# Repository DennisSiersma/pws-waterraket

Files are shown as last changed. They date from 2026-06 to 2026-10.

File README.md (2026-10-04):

# PWS Waterraket

Profielwerkstuk natuurkunde (vwo): welke factoren bepalen de prestatie
(apogeumhoogte) van een waterraket? Met testplan, lanceerinstallatie,
meet-logsheets en een zelfgebouwde vluchtcomputer.

## Gekozen hardware (route B)

Vluchtcomputer: **Waveshare ESP32-S3-Touch-LCD-1.69** met een losse druksensor.
De eerdere XIAO-opzet is niet gekozen; die bestanden blijven staan als alternatief
en ter verantwoording van de keuze, maar worden niet onderhouden.

| Functie | Onderdeel | Adres |
|---|---|---|
| Microcontroller + scherm + touch | Waveshare ESP32-S3-Touch-LCD-1.69 | touch 0x15 |
| Versnelling (stuwprofiel) | QMI8658, onboard | 0x6B |
| Hoogte (apogeum) | BMP388 **of** BME680, los bijgeprikt | 0x76 / 0x77 |
| Voeding | 3,7 V LiPo met MX1.25-stekker | - |
| Fles (standaard) | Fernandes Cherry Bouquet 1,5 L | volledig cilindrisch, diameter 88,5 mm |

De firmware herkent bij het opstarten zelf welke druksensor er zit en stelt zich
daarop in. De BMP388 is de betere keuze voor de vluchten; de BME680 werkt ook maar
is trager.

> **Bouw je dit na? Lees eerst [`docs/HANDLEIDING.md`](docs/HANDLEIDING.md).**
> Daarin staan de valkuilen die ons tijd hebben gekost: de CS/CSB-jumper op de
> sensor, de juiste USB-poort bij het flashen, de PWR-knop voor accuvoeding, en de
> koppeling tussen oversampling en meetfrequentie.

## Meetdata analyseren

Open [`webapp/index.html`](webapp/index.html) in een browser en sleep de CSV-bestanden
erop die je van de vluchtcomputer hebt gedownload. De applicatie draait volledig in
de pagina: geen server, geen bouwstap, geen internet. Ze berekent apogeum, snelheid,
versnelling, stuwtijd, vluchttijd en daalsnelheid met de bijbehorende meetonzekerheid,
vergelijkt vluchten op een instelvariabele, zet het theoretische model ernaast en
levert PNG's, een CSV en een afdrukbaar rapport voor in het verslag.

Bij elke berekende waarde staat de formule in de interface zelf. Ze staan ook
bij elkaar in [`docs/PWS_Waterraket_Analyse_Formules.md`](docs/PWS_Waterraket_Analyse_Formules.md),
geschikt als bijlage bij het profielwerkstuk.

Testdata met een exact bekende uitkomst en de volledige controlereeks:

```bash
node test/genereer_vlucht.js --alles && node test/gauntlet.js
```

## Inhoud

```
webapp/
  index.html                                           <- hier begint de analyse
  stijl.css
  js/kern/                                             rekenwerk: csv, filter, grootheden, theorie
  js/ui/                                               grafieken, opslag, export
test/
  genereer_vlucht.js                                   synthetische vluchten met bekende uitkomst
  gauntlet.js                                          de vaste controlereeks
  browsertest/index.html                               controles die een browser nodig hebben
docs/
  PWS_Waterraket_Analyse_Formules.md                   Formules en aannames van de analyse
  HANDLEIDING.md                                       Bouw, gebruik en probleemoplossing
  PWS_Waterraket_Onderzoeksplan.docx                   Onderzoeksplan (theorie, testplan, BOM)
  PWS_Waterraket_Lanceerinstallatie.docx               Launcher: tekening, onderdelen, bronnen
  PWS_Waterraket_Bouwtekening_Launcher_SplitCollar.svg Detailtekening launcher (split-collar, aanbevolen)
  PWS_Waterraket_Bouwtekening_Launcher_Clark.svg       Detailtekening launcher (schuifkraag, oudere variant)
  PWS_Waterraket_Bouwtekening_Lanceerinstallatie.svg   Overzichtstekening launcher
  PWS_Waterraket_Bedradingsschema_S3-Touch.svg         Bedrading van de gekozen opstelling
  PWS_Waterraket_Bedradingsschema_XIAO.svg             (alternatief, niet gebruikt)
firmware/
  PWS_Waterraket_ESP32-S3-Touch_sketch.ino             <- deze gebruiken
  PWS_Waterraket_ESP32_sketch.ino                      (alternatief, niet gebruikt)
hardware/
  PWS_Waterraket_Houder.stl                            Payloadhouder (bord + sensor + accu)
  PWS_Waterraket_Vinnen_klein/midden/groot.stl         Fin can, drie maten met bekend vinoppervlak
  PWS_Waterraket_Recovery_Romp.stl / _Deur.stl         Recovery: parachutekamer met servo-zijdeur
  PWS_Waterraket_Recovery_Schot_A/B.stl                Los schotje in twee helften (past zo door de draad)
  PWS_Waterraket_Tray_A/B.stl                          Elektronicatray in twee helften: A bord, B accu+sensor
  PWS_Waterraket_Neus_Ogief/Kegel/Elliptisch.stl       Verwisselbare schroefneuzen, drie vormen
  PWS_Waterraket_Testneus.stl                          Simpele TPU-neus voor testvluchten zonder parachute
  PWS_Waterraket_NozzleOpzet_04..09mm.stl              Nozzles: opzetstuk over de originele dop (voorkeur)
  PWS_Waterraket_NozzleLijm_04..09mm.stl               Nozzles: op de originele dop te lijmen
  PWS_Waterraket_NozzleSteunring_04..09mm.stl          Nozzles, 4 t/m 9 mm (zitting op de steunring)
  archief/                                             niet gebruikte ontwerpen, met uitleg waarom
  genereer_*.py                                        Generatorscripts (maten bovenin aanpasbaar)
logsheets/
  PWS_Waterraket_Logsheets.xlsx                        Vluchtlog + hoogte-/spreidingsberekening
```

## Bediening in het kort

| Scherm | BOOT kort | BOOT lang |
|---|---|---|
| HOME | INFO | START (kalibreren + scherp) |
| INFO | terug | raaktest |
| Raaktest | terug | ijken (>4 s: ijking wissen) |

Na de vlucht opent VERZEND een wifi-netwerk (`Waterraket` / `raket1234`) waarop je
de meting als CSV downloadt. Het INFO-scherm toont live druk, hoogte, temperatuur
en versnelling, zodat je kunt testen zonder te lanceren.

## Meetmethode

Primair: barometrische apogeumhoogte, gevalideerd met de trigonometrische
grondmeting (hoek + afstand). De QMI8658 geeft het versnellings- en stuwprofiel.

## Veiligheid

Alleen frisdrank-PET-flessen; begin laag (3-4 bar), nooit boven ~7 bar; minimaal
10 m afstand, lanceren via een touw, veiligheidsbril. 3D-geprinte drukdelen eerst
vol water achter een afscherming testen. LiPo's alleen onder toezicht laden en de
polariteit controleren vóór het insteken.

## Bronnen

De volledige bronnenlijst staat in het hoofdstuk "Bronnen" van het onderzoeksplan.

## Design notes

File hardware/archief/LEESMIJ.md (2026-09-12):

# Archief: niet gebruikte ontwerpen

Deze bestanden zijn NIET in gebruik. Ze staan hier bewaard omdat ze de
ontwerpstappen laten zien, en dat is verantwoording waard in het verslag.
Print hieruit niets; de werkende versies staan een map hoger.

## Nozzles: vier varianten die het niet werden

De eis was dat de nozzle kaarsrecht op de fles staat. Een scheve nozzle geeft
scheve stuwkracht en dus een raket die niet zuiver vliegt.

| Bestanden | Aanpak | Waarom afgevallen |
|---|---|---|
| `PWS_Waterraket_Nozzle_04..10mm.stl` | insteek in een geboorde originele dop | goede aanpak, maar past niet in onze Gardena-launcher |
| `PWS_Waterraket_Nozzledop_*.stl` | volledig geprinte dop met PCO1881-draad | de geprinte draad bepaalt de stand en die staat scheef |
| `PWS_Waterraket_NozzleGardena_*.stl` | Gardena-steel plus geleidingspen in de flesmond | de pen maakt een diepe sleuf waar support in moet dat je er niet uit krijgt |
| `PWS_Waterraket_NozzleGardenaDop_*.stl` | Gardena-steel in een geboorde originele dop | werkbaar alternatief, maar nooit getest; de steunring-versie was beter |

De gemene deler van de mislukkingen: telkens werd de schroefdraad meegeprint, en
de vier losse draadsegmenten van een PCO1881-hals zijn gemaakt om aan te trekken,
niet om iets haaks te positioneren.

**Wat het wel werd:** `PWS_Waterraket_NozzleSteunring_*.stl`, met een zitting op
de steunring van de fles (33,07 mm in plaats van 21,74 mm), waardoor de zitting
veel breder is en de geleidingspen overbodig werd.

## Ook vervallen

- De losse neuskegel (bay en tip) is vervangen door de recovery-romp met
  verwisselbare schroefneus.
- De adapter naar het Raketfued Phoenix 3D-systeem is vervallen; dat principe is
  nagebouwd in de eigen parametrische pijplijn.

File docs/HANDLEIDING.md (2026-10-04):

# Handleiding vluchtcomputer waterraket

Praktische bouw-, gebruik- en probleemoplossingsgids voor de vluchtcomputer.
Alle hier genoemde instellingen staan bovenin `firmware/PWS_Waterraket_ESP32-S3-Touch_sketch.ino`.

## 1. Hardware

| Onderdeel | Keuze | Opmerking |
|---|---|---|
| Microcontroller | Waveshare ESP32-S3-Touch-LCD-1.69 | ESP32-S3R8, 240x280 LCD, CST816 touch |
| Versnelling | QMI8658 (onboard, 0x6B) | klipt bij +/-16 g tijdens de stuwfase |
| Hoogte | BMP388, BMP390(L) of BME680 (0x76/0x77) | firmware herkent ze automatisch |
| Voeding | 3,7 V LiPo, MX1.25-stekker | laden via USB-C |
| Fles | Fernandes Cherry Bouquet 1,5 L | volledig cilindrisch, diameter 88,5 mm |

De BMP388 is de betere keuze voor de vluchten (sneller, lagere ruis, gemaakt voor
hoogtemeting). De BME680 werkt ook, maar is trager omdat hij meer grootheden meet.

## 2. Solderen

Slechts vier draden tussen sensor en bord; de rest zit al op het bord.

| Sensor | Bord (randpad) |
|---|---|
| VCC | 3V3 (**niet** 5V) |
| GND | G |
| SDA | SDA (GPIO11) |
| SCL | SCL (GPIO10) |

Twee jumpers op de sensormodule zelf, en die zijn niet optioneel:

- **CSB (BMP388) / CS (BME680) naar VCC** - dwingt I2C af. Zwevend laten betekent
  dat de chip in SPI-modus blijft: hij geeft dan wel een acknowledge op de bus,
  maar levert alleen nullen (chip-ID 0x00). Dit heeft ons een sensor gekost die we
  ten onrechte voor defect hielden.
- **SDO naar GND (adres 0x76) of naar VCC (0x77)** - niet laten zweven.

Trek-ontlasting: een druppel hete lijm of een tiewrap over de draadbundel bij het
bord. Soldeerverbindingen op castellated pads breken anders bij de lanceerklap.

## 3. Flashen

Arduino IDE, board `ESP32S3 Dev Module`, PSRAM `OPI PSRAM`, `USB CDC On Boot:
Enabled`, flash 16MB.

Libraries: GFX Library for Arduino, SensorLib, Adafruit BMP3XX, Adafruit BME680
(+ Adafruit Unified Sensor en BusIO).

**Kies de juiste poort.** Dit bord heeft geen USB-serieel-chip: USB-C gaat
rechtstreeks naar de native USB van de ESP32-S3. Het meldt zich daarom als
*USB JTAG/serial debug unit*, bij ons `/dev/cu.usbmodem101`. Hangt er nog een
ander bord aan de Mac (met CH340/CH9102), dan verschijnt dat als *USB Single
Serial* en gaat de upload dáárheen: de upload slaagt, maar je raket-bord blijft
zijn oude firmware draaien. Bij twijfel het andere bord loskoppelen.

Blijft "Hard resetting via RTS pin..." staan: dat is normaal bij native USB (er is
geen RTS-lijn). Lukt de upload niet, houd dan **BOOT** ingedrukt, tik **RST** aan,
laat BOOT los.

## 4. Bediening

Bij het opstarten verschijnt kort een blauw **BOOT OK**-scherm met het
compileertijdstip. Zo weet je zeker dat de nieuwe firmware draait.

| Scherm | Touch | BOOT kort | BOOT lang (>1,2 s) |
|---|---|---|---|
| HOME | START / INFO | INFO | START (kalibreren + scherp) |
| INFO | TERUG | terug | raaktest |
| Raaktest | kruisje tekenen | terug | ijken (>4 s: ijking wissen) |

Vluchtverloop: START kalibreert (50 drukmetingen op de grond) en gaat naar GEREED.
Stijgt de hoogte boven 3 m, dan begint het loggen op 50 Hz naar intern flash.
Na de landing (of na 30 s) volgt het RESULTAAT-scherm met apogeum, maximale
versnelling en vluchttijd. Via VERZEND opent het bord een wifi-netwerk
(`Waterraket` / `raket1234`); daarop het getoonde IP-adres openen geeft de CSV.

## 5. Accu

Het bord start **niet** vanzelf op de accu. Sluit de accu aan en druk op de
**PWR-knop**; daarna houdt de firmware de voeding vast via SYS_EN (GPIO35 volgens
het schema; met `BOARD_ALT 1` schakel je naar GPIO41). Controleer de polariteit van
de MX1.25-stekker tegen de markering op het bord vóór het insteken.

## 6. Scherm en touch

- Het glas heeft **afgeronde hoeken**: houd tekst en knoppen binnen `SAFE_M` (22 px).
- `LCD_OFFY` hoort **20** te zijn. Met 0 loopt de titel van het scherm.
- De touch rapporteert y ongeveer **22 px hoger** dan waar je tikt. Dat is een vaste
  verschuiving en staat als standaard in de code (`calBy = -22`), geen schaalfout.
- De touch komt niet hoger dan ruw y=278, dus de onderste ~24 px zijn onbereikbaar.
  Alle knoppen staan daarom boven die grens.

## 7. Instellingen die bij elkaar moeten passen

Oversampling en meetfrequentie van de druksensor zijn gekoppeld. 8x oversampling
kost ongeveer 27 ms per meting en haalt 50 Hz (20 ms) niet: de sensor geeft dan een
configuratiefout en levert géén metingen. Daarom staat de druk op 4x en de
temperatuur op 1x.

## 8. Meetkundige aandachtspunten

- De hoogte op het INFO-scherm is gerekend tegen de standaarddruk van 1013,25 hPa
  en is dus **geen** hoogte boven de grond. Pas na kalibreren (START) is de hoogte
  relatief ten opzichte van het lanceerpunt.
- Kalibreer **vlak voor elke lancering**: de luchtdruk verandert gedurende de dag.
- Boor een klein **statisch gat** in de neuskegel ter hoogte van de sensor, zodat hij
  de omgevingsdruk meet en niet de dynamische druk van de luchtstroom.
- De versnellingsmeter klipt bij 16 g. Voor het apogeum maakt dat niet uit (daar is
  v ongeveer 0); voor het stuwprofiel is het een bekende beperking.

## 9. Payloadhouder (3D-print)

`hardware/PWS_Waterraket_Houder.stl` is direct te slicen. Print met de bodem op
het bed; supports zijn niet nodig. PETG is voor buitengebruik beter dan PLA.

Het sensorvak is bewust ruim (17 x 23 x 7,5 mm) zodat zowel de BMP388 als de
BME680 erin past; zet de module vast met schuim of dubbelzijdige tape. Een
barometer hoeft niet strak te klemmen, hij moet juist lucht kunnen zien - daarom
zitten er twee ventilatieopeningen in dat vak.

Maten aanpassen (bijvoorbeeld na het meten van je eigen bord of accu): pas de
waarden bovenin `hardware/genereer_houder.py` aan en draai:

```
python3 -m venv .venv
./.venv/bin/pip install trimesh manifold3d numpy
./.venv/bin/python hardware/genereer_houder.py
```

Maten volgens de officiele maatschets van Waveshare:

| Maat | Waarde |
|---|---|
| Buitenmaat module (incl. zwarte rand) | 41,13 x 33,13 mm |
| Kale print | 38,48 x 31,07 mm |
| Totale dikte | 6,60 mm (scherm 3,82 +/- 0,2) |
| Schermglas | 32,63 x 27,97 mm |

De zwarte rand steekt ongeveer 1,3 mm per zijde buiten de print uit; die
buitenmaat bepaalt de pasvorm. De clips pakken 2 mm over die rand, ruim binnen
de ~4,2 mm brede rand, dus ze komen niet op het glas.

## 10. Keuze van de lanceerinstallatie

Gebouwd wordt de **split-collar cable-tie launcher**: kabelbinders rondom de
flessenhals, gehouden door een kraag die in twee helften is gezaagd en met een
zelfklemtang wordt dichtgehouden. Het trekkoord zit aan het ontgrendellipje van
die tang.

Waarom niet de twee bekendere varianten:

- **Gardena-koppeling**: beperkt de nozzlediameter (ook met een 3D-geprinte
  nozzle niet boven ~9 mm), is lastig te combineren met een launch tube en de
  plastic koppelingen zijn niet gemaakt voor hoge druk. Omdat nozzlediameter een
  van de onderzoeksvariabelen is, valt deze af.
- **Klassieke Clark met schuifkraag**: goed principe, maar de kracht om te
  ontgrendelen loopt op met de flesdruk. Bij hogere druk kan het trekkoord breken
  of de installatie kantelen, en dat verandert de lanceerhoek per meting. Precies
  de spreiding die je in een meetreeks niet wilt.

Bij de gedeelde kraag klap je hem open in plaats van hem tegen de wrijving in weg
te schuiven, dus de benodigde kracht is nagenoeg onafhankelijk van de druk.

Let op voor het verslag: de **launch tube** is zelf een variabele. Hij geeft extra
hoogte en meer consistentie, maar alleen als je lengte en diameter over alle
metingen gelijk houdt. Noteer ze.

## 11. Druksensor: welke past?

De firmware leest bij het opstarten het chip-ID uit en stelt zichzelf in:

| Chip-ID | Sensor | Register |
|---|---|---|
| 0x50 | BMP388 | 0x00 |
| 0x60 | BMP390 / BMP390L (o.a. DFRobot) | 0x00 |
| 0x61 | BME680 | 0xD0 |

BMP388 en BMP390 delen dezelfde library (Adafruit BMP3XX) en dezelfde aansturing;
de DFRobot-library is niet nodig. De BMP390L is de industriele opvolger van de
BMP388: betere temperatuurstabiliteit, lagere drift en minder ruis, dus voor
apogeummeting de beste van de drie.

Aansluiten is voor alle drie gelijk: VCC naar 3V3, GND naar G, SDA naar GPIO11,
SCL naar GPIO10.

Bij **kale breakout-printjes** (Fermion-type) moet je zelf CSB/CS naar VCC leggen
om I2C af te dwingen, en SDO vastzetten: naar GND is adres 0x76, naar VCC 0x77.
Bij **Gravity-modules** van DFRobot is dat al op de print geregeld (standaard
0x77) en volstaan de vier draden.

## 12. Neuskegel met payloadruimte (VERVALLEN)

Deze losse neuskegel is vervangen door de recovery-romp met verwisselbare
schroefneus (hoofdstuk 22). De bestanden zijn uit de repo verwijderd; de tekst
hieronder blijft staan als verantwoording van de ontwerpstappen.

Twee geprinte delen, te maken met `hardware/genereer_neuskegel.py`:

| Deel | Bestand | Massa (PLA) |
|---|---|---|
| Romp met payloadruimte | `PWS_Waterraket_Neuskegel_Bay.stl` | ~38 g |
| Ogief-punt | `PWS_Waterraket_Neuskegel_Tip.stl` | ~20 g |

De fles staat neck-down, dus de kegel zit op de **bodem** van de fles. De romp
schuift 32 mm over de fles en heeft daarboven 92 mm vrije ruimte.

**De houder staat rechtop**, met het platte vlak evenwijdig aan de raketas, tussen
vier ribben. Dat is bewust: liggend zou de houder (71,4 x 81,7 mm) een diameter van
108 mm vragen en dat past niet in een fles van circa 88 mm. Rechtop hoeft alleen de
breedte van 71,4 mm in de doorsnede te passen.

**Statische poorten**: vier gaten van 3 mm, 55 mm boven het tussenschot, precies
waarvoor ze bedoeld zijn: de barometer meet zo de omgevingsdruk en niet de
dynamische druk van de langsstromende lucht. Zorg dat de sensor op ongeveer die
hoogte in de houder zit.

Door het tussenschot zitten twee gaten van 4 mm voor een schokkoord of
parachutelijn.

**Standaardfles: Fernandes Cherry Bouquet 1,5 L.** Volledig cilindrisch, wat
beter is dan een getailleerde fles: manchet en neuskegel liggen overal aan. De
diameter is bepaald uit de omtrek (278 mm / pi = 88,5 mm); dat is op een ronde
vorm nauwkeuriger dan een schuifmaat. `FLES_D` staat op 88,5. Kies je ooit een
andere fles, pas de waarde bovenin het script aan en draai opnieuw:

```
cd hardware && ../../.venv/bin/python genereer_neuskegel.py
```

**Printen**: beide delen staand, zonder supports. De wand is 1,6 mm, dus twee
perimeters volstaan. PETG is taaier dan PLA en breekt minder snel bij de landing.
De punt is hol; print hem met weinig infill.

**Massa telt mee.** Samen circa 58 g in de neus. Dat helpt de stabiliteit (het
zwaartepunt schuift naar voren, weg van het drukpunt), maar kost hoogte. Houd de
massa over alle metingen gelijk en noteer hem, anders zit dat verschil in je
resultaten.

**Vinnen** komen niet uit dit project: gebruik de set van Marimo Labs op
Printables (`printables.com/model/86434`). Die is ontworpen met vrije ruimte voor
de klemmen van een cable-tie launcher en heeft drie vinmaten, wat handig is als je
vinoppervlak later als variabele wilt gebruiken.

## 13. Vinnen (fin can)

`hardware/genereer_vinnen.py` maakt een manchet met drie vinnen die om de fles
klemt. Geen lijm nodig: een tiewrap in de groef onderaan houdt hem vast. Onderaan
blijft 12 mm vrij voor de klemmen van de split-collar launcher.

Kant-en-klare modellen van internet passen vaak niet: veel populaire sets zijn
gemaakt voor Amerikaanse flesmaten (1L Polar Seltzer, 2L US-flessen). Deze
manchet gebruikt dezelfde `FLES_D` als de neuskegel, dus alles past op jouw fles.

Drie maten met **bekend vinoppervlak**, zodat je vinoppervlak als gecontroleerde
variabele kunt gebruiken:

| Maat | Spanwijdte | Per vin | Totaal (3 vinnen) | Massa |
|---|---|---|---|---|
| klein | 45 mm | 19,4 cm2 | 58,1 cm2 | ~42 g |
| midden | 58 mm | 29,0 cm2 | 87,0 cm2 | ~51 g |
| groot | 72 mm | 41,8 cm2 | 125,3 cm2 | ~63 g |

De vinwortel loopt door de hele manchetwand, en de manchet is altijd hoger dan de
wortel, zodat er geen losse flap boven uitsteekt. Alle drie zijn gecontroleerd op
waterdichtheid en op samenhang (een geheel, geen losse delen).

**Printen**: manchet rechtop, geen supports. PETG of TPU is taaier dan PLA, dat
bij een harde landing breekt.

**Conische zitting.** De fles is nergens exact cilindrisch: hij loopt over de
hele lengte licht taps. Bij de vinnen (halszijde) gaat de omtrek over ~30 mm van
264 naar 276 mm, oftewel diameter 84,0 naar 87,9 mm. De binnenboring van de
manchet heeft diezelfde conus, met 0,4 mm speling.

Let op het verschil met de andere delen: neuskegel en recovery-romp schuiven over
de **flesbodem** en houden 88,5 mm aan; alleen de vinnen gebruiken 87,9 mm. Voordelen boven een cilindrische manchet met een gelijmde opvulring:

- geen lijm op PET (dat hecht slecht, en juist daar grijpen de krachten aan)
- de manchet wigt zichzelf vast en staat daardoor altijd recht
- hij kan niet naar de hals zakken: de conus loopt dicht
- de axiale positie is reproduceerbaar, wat scheelt in de meetspreiding

**Monteren**: schuif de manchet van bovenaf over de fles en duw hem omlaag tot
hij klemt op de conus. Zet daarna de tiewrap in de groef vast. Zit hij te vroeg
klem, verhoog `FLES_SPEL` naar 0,6; zakt hij te ver door, verlaag naar 0,25.

Meet je een andere fles op, pas dan `FLES_D`, `FLES_D2` en `FLES_TAPS` aan.

Wil je vier vinnen in plaats van drie, zet `VIN_N` op 4: stabieler, maar meer
weerstand en meer massa.

## 14. Recovery: verkende route (vervallen)

We hebben eerst geprobeerd het Raketfued Phoenix 3D d78m-systeem te gebruiken via
een zelfgemaakte adapter (fles 88,5 mm naar hun 1L-flesvorm). Die combinatie
werkte in de praktijk niet prettig; de adapter is uit de repo verwijderd. Het
Phoenix-principe zelf, een vlakke zijdeur in een unibody-romp, is overgenomen in
het eigen ontwerp hieronder.

## 15. Recovery: eigen zijdeur-systeem

Zoals in hoofdstuk 14 beschreven bouwt
`hardware/genereer_recovery.py` het zijdeur-principe van Phoenix na in onze eigen
parametrische pijplijn, met een belangrijk verschil: **de vluchtcomputer opent de
deur op het gemeten apogeum** in plaats van een mechanische opwindtimer.

Opbouw (een romp, van onder naar boven): schuifrand over de fles, elektronica-
ruimte met rails en statische poorten (identiek aan de neuskegel), parachutekamer
110 mm met vlakke zijdeur, en bovenaan de insteekrand waar de bestaande
ogief-punt (`PWS_Waterraket_Neuskegel_Tip.stl`) op past.

De deur ligt vlak in de wand (geen randen die de uitworp hinderen), is getrapt
(dunne flens rust op een kozijnrand van 2,5 mm, dikke kern valt in de opening),
scharniert onderaan op een stukje 1,75 mm filament en heeft bovenaan een lip die
door een sleuf naar binnen steekt. Een **SG90-servo** op het plankje boven de
deur is de grendel: de hoorn valt in het gat van de lip. Bij het apogeum draait
de servo weg en trekt een elastiekje (van een haakje op de deur naar de romp,
over het scharnier) de deur open.

Aansluiting servo: signaal op **GPIO18** (randpad "18"), voeding op de 5V- en
G-pads. De firmware-aansturing volgt nog.

Numeriek gecontroleerd: romp en deur waterdicht; overlap deur-romp, houder-romp
en tip-romp alle exact 0; scharniergaten coaxiaal na plaatsing.

Nog te doen bij assemblage (niet blind te printen): de servohoorn op lengte
maken zodat hij het lipgat haalt, en de elastiekspanning afstellen. Reken op een
bankproef voor de eerste vlucht.

De fles schuift **50 mm** diep in de schuifrand; die verbinding vangt de
parachuteklap op. Vastzetten met PU-lijm of epoxy rondom, of met drie zelftappers
door rand en fleswand als je de romp verwisselbaar wilt houden.

**Materiaal: PETG.** PLA wordt boven ~55 graden zacht (een raket in de zomerzon
of in de auto haalt dat) en breekt bros bij de landing; PETG is taaier, blijft
vormvast tot ~75 graden en hecht laag-op-laag beter, wat telt voor de
scharnierogen en de kozijnrand. ABS/ASA voegt hier niets toe en kromtrekt bij
lange smalle prints; TPU is te slap voor een dragende romp (wel goed voor de
vinnen). Gebruik PLA hooguit voor een snelle pasproef.

Printen: romp staand zonder supports, 15-20% infill (~65 g in PETG), deur plat op
de rug (~7 g). Zet de **koeling hoog en brugsnelheid laag** voor de overspanning
boven de deuropening: dat is een gebogen brug van 58 mm, en PETG zakt daar
sneller door dan PLA. Een pontje eronder uit de slicer mag ook; dat breekt er na
het printen zo uit.

## 16. Parachute-uitworp in de firmware

De servo hangt aan **GPIO18** (randpad "18"), aangestuurd via LEDC-hardware-PWM
(50 Hz), zonder servo-library.

**Wanneer gaat de deur open?** Tijdens het loggen wordt elke meting getoetst:

```
open als   maxAlt > 8 m  EN  curAlt < maxAlt - 1,5 m      (voorbij het apogeum)
of als     vluchttijd > 12 s                              (noodklok)
```

De eerste voorwaarde is de echte: pas als de hoogte 1,5 m onder het maximum is
gezakt, is de raket aantoonbaar over de top. Dat is bewust niet "hoogte daalt",
want een enkele ruispiek zou de deur dan al openen. De eis van 8 m voorkomt
uitworp bij een mislukte lancering. De noodklok is het vangnet: gaat de detectie
om welke reden dan ook mis, dan opent de deur sowieso na 12 s.

Instelbaar bovenin de sketch: `SERVO_DICHT` / `SERVO_OPEN` (hoeken),
`DEPLOY_DROP_M`, `DEPLOY_MIN_M`, `DEPLOY_MAX_S`.

**Bankproef zonder te vliegen**: INFO-scherm, BOOT ingedrukt houden tussen 1,2 en
3 s. De deur gaat open, 3 s later grendelt hij weer. (Langer dan 3 s indrukken
opent nog steeds de raaktest.) Bij het scherpstellen (START) grendelt de deur
automatisch voor de nieuwe vlucht.

De servo wordt 4 s na elk commando **stroomloos** gezet: dat scheelt stroom en
voorkomt het typische servogebrom. De grendel houdt mechanisch, niet door
motorkracht.

**Servo: MG90S** (metalen tandwielen; de plastic SG90 strippen op den duur).
Oranje draad naar pad 18, bruin naar G. Meet eerst of het 5V-pad ook op accu
spanning geeft; zo niet, voed de servo dan rechtstreeks van de accu (BAT).
Sluit hem **niet** op 3V3 aan: de piekstroom laat het bord resetten.

## 17. Testneus (TPU, zonder parachute)

`hardware/genereer_testneus.py` maakt een eenvoudige neus uit een deel, bedoeld
voor de eerste testvluchten: werkt de lancering, vliegt de raket recht, kloppen
de vinnen. Geen parachutekamer, geen elektronica.

**Ontworpen voor hard TPU (95A/98A).** Zonder parachute is de landing een klap;
TPU vervormt en veert terug waar PLA en PETG breken. Dat maakt vrij lanceren
mogelijk zonder na elke vlucht te lijmen.

De maten zijn daarop aangepast, anders dan bij de harde onderdelen:

| Maat | Waarde | Waarom |
|---|---|---|
| Speling op de fles | 1,4 mm | TPU grijpt sterk; met 1,0 krijg je hem er niet meer af |
| Wanddikte | 2,0 mm | 4 banen van 0,5 mm; dunner wordt slap |
| Schuifrand | 45 mm | de wrijving van TPU doet hier het klemwerk, geen lijm nodig |
| Tipradius | 3 mm afgerond | een scherpe punt scheurt in TPU en is bovendien gevaarlijk |

Verder: drie ontluchtingsgaten in de schuifrand en een in het tussenschot, zodat
de lucht bij het opschuiven weg kan. De punt is massief (de holte stopt waar de
wand te dun zou worden); daardoor zit 65% van het materiaal in de onderste helft
en ligt het zwaartepunt op 66 mm, wat gunstig is voor de stabiliteit.

Afmetingen 93,9 x 93,9 x 158 mm, ongeveer 65 g in TPU bij 20% infill.

**Printinstellingen TPU**: 20-25 mm/s, retractie zo goed als uit, direct drive bij
voorkeur, geen supports (de vorm heeft nergens een overhang die dat vraagt).
Print langzaam op de eerste lagen van de schuifrand.

Let op: deze neus weegt anders dan de recovery-romp. Houd testvluchten en
meetvluchten dus gescheiden, of noteer per vlucht welke neus erop zat.

## 18. Nozzles: twee ontwerpen

De nozzle bepaalt hoe snel het water eruit gaat en is een onderzoeksvariabele.
Voorwaarde: hij moet KAARSRECHT op de fles staan, anders staat de stuwkracht
scheef en vliegt de raket niet zuiver.

**Waarom geprinte doppen scheef gaan staan.** De PCO1881-hals heeft vier losse
draadsegmenten, bedoeld om een dop aan te trekken, niet om iets haaks te
positioneren. Een geprinte draad heeft laaglijnen en een naadlijn en loopt
daardoor ergens vroeg aan. Hij richt zich dan uit op de draad in plaats van op
de flesmond.

Er staan nu twee oplossingen in de repo. Print ze allebei en vergelijk ze; dat
levert meteen een mooie paragraaf voor het verslag op.

### A. Insteek in een geboorde originele dop (`genereer_nozzles.py`)

Maten 4 tot en met 10 mm. Een originele dop is spuitgegoten en zit altijd haaks;
wij printen alleen het gekalibreerde gaatje. Boor 16,0 mm in de dop, duw de
nozzle er van BINNENUIT in (flens aan de waterkant, dan drukt de druk hem
vanzelf tegen de dop) en dicht af met wat siliconenkit of PTFE-tape. Er steekt
15 mm geleiding in de flesmond.

### B. Volledig geprinte dop met schroefdraad (`genereer_nozzledoppen.py`)

Maten 4, 6, 8 en 10 mm. Draad volgens ISBT PCO 1881: spoed 2,7 mm, een
draadgang, draad 27,43 / kern 24,94 / halsboring 21,74 mm. Drie maatregelen
tegen scheefstaan: een geleidingsbossing van 12 mm in de flesmond (dit is de
belangrijkste), een vlakke zitting op de flesrand met O-ringgroef (23 x 2 mm),
en vrijloop boven de draad zodat hij niet op de draad kan bottomen.

Print met de DICHTE KANT OP HET BED, opening naar boven: de draad zit dan
binnen en print als flauwe overhang, zonder supports. Reken op een proefprint
voor de pasvorm: te strak of te los stel je bij met `DRAAD_SPEL`, in stappen van
0,1 mm. De spoed van 2,7 mm blijft ongewijzigd.

### Controle op haaksheid

Zet de fles met nozzle op zijn kop op een vlakke tafel en draai de fles rond.
Blijft de nozzle op zijn plek, dan staat hij recht. Wandelt hij, dan zit er
speling. Doe dit voor beide varianten en noteer het verschil.

### C. Gardena-nozzle die recht staat (`genereer_nozzles_gardena.py`)

**Dit is de versie voor onze launcher.** De Gardena-koppeling is bij ons ook het
vergrendelmechanisme, dus de nozzle moet een Gardena-steel hebben. De varianten A
en B hierboven gaan uit van een launcher die de fleshals klemt en passen dus niet.

Vastgesteld probleem bij de nozzles van Raketfued: **de dop raakt de flesrand
niet**. Hij hangt volledig aan de geprinte schroefdraad. De vier losse
draadsegmenten van een PCO1881-hals zijn gemaakt om aan te trekken, niet om iets
haaks te positioneren, en dat is met beter printen niet op te lossen. Bijkomend
nadeel: zonder contact op de rand is er ook geen vlakke afdichting.

Deze versie neemt hun Gardena-steel over (opgemeten uit hun `Nozzle_8mm.stl`,
per 0,4 mm hoogte; onze steel komt tot op 0,1 mm overeen) en zet er drie
maatregelen op:

| Maatregel | Maat | Effect |
|---|---|---|
| Geleidingsbossing | 21,3 mm, 12 mm lang | steekt in de flesmond (21,74) en dwingt hem recht |
| Vlakke zitting | landt wel op de flesrand | bepaalt de stand, niet de draad |
| O-ringgroef | 22,8 tot 26,8 mm | dicht af op een vlak; O-ring 23 x 2 mm |
| Draadvrijloop | boven de draad | kan niet op de draad bottomen |

Maten 4 tot en met 9 mm. **Negen is de bovengrens**: bij de O-ringgroef is de
Gardena-steel maar 11,4 mm dik, dus daarboven wordt de wand te dun. Dat is meteen
de bovengrens van het onderzoeksbereik zolang we een Gardena-launcher gebruiken.

Printen: staand, Gardena-kant op het bed, 0,15 mm laagjes, geen supports,
olifantenpoot-compensatie aan, PETG.

**Controleer bij de eerste print of de dop nu WEL op de flesrand landt.** Blijft
er een spleet, dan grijpt de draad te vroeg: verhoog `DRAAD_START` met 0,5 mm en
print opnieuw. Dat is de kern van de hele oplossing.

### D. Gardena-nozzle in een geboorde originele dop (`genereer_nozzles_gardenadop.py`)

**Dit is de werkende oplossing.** Variant C hierboven faalde alsnog: de
binnendraad en de geleidingsbossing vragen support op een plek waar je niet bij
kunt, en achtergebleven supportresten trekken de nozzle opnieuw scheef.

De rode draad door alle mislukkingen was hetzelfde: **de schroefdraad werd
meegeprint**. Hier doen we dat niet meer. Een originele flesdop is spuitgegoten,
zit altijd haaks op de flesmond en dicht al af met zijn eigen liner. Wij printen
alleen de Gardena-steel met de gekalibreerde doorlaat.

Waarom dit wel lukt:

- **Geen geprinte draad**, dus ook geen draad die de stand bepaalt.
- **Geen inwendig support.** Nagerekend: alle overhangen liggen op straal 5,8 tot
  7,8 mm, dus aan de buitenkant, en het zijn ringvormige richels van hooguit
  2 mm. De doorlaat zelf is een rechte boring zonder overhang. Zet er toch iets
  support, dan kun je er met je vingers bij.
- **Zelfdichtend.** De flens zit binnen in de dop, aan de waterkant. Hoe hoger de
  druk, hoe steviger de flens tegen de dop wordt gedrukt. Trekken aan het
  Gardena-koord kan hem er niet uittrekken.

Montage: boor 16,0 mm midden in een originele dop (dop vastklemmen, langzaam
boren, rand nawerken met een mesje), duw de nozzle er van BINNENUIT in zodat de
flens aan de waterkant blijft, dicht af met een dun laagje siliconenkit of
PTFE-tape, laten uitharden, dop op de fles.

Meet twee maten aan jouw dop na en pas ze zo nodig aan bovenin het script:
`DOP_T` (dikte van de bovenkant, staat op 2,2) en `DOP_BINNEN_D` (vrije
binnendiameter, staat op 25,0).

Maten 4 tot en met 9 mm; 9 blijft de bovengrens vanwege de Gardena-steel.

Printen: Gardena-kant op het bed, 0,15 mm laagjes, GEEN supports, PETG.

### E. Gardena-nozzle die rust op de STEUNRING (`genereer_nozzles_steunring.py`)

Idee van Dennis, en het beste van de vijf. Niet uitrichten op de flesrand of op
een pen in de flesmond, maar op de **steunring**: die brede kraag onder de
schroefdraad.

Waarom dat beter werkt:

- De ring is **33,07 mm** in doorsnede tegen 21,74 mm voor de flesmond. Een
  bredere zitting verzet zich veel sterker tegen kantelen, want de hefboom is
  anderhalf keer zo groot.
- De ring is spuitgegoten, dus vlak en haaks op de as.
- Er is **geen geleidingsbossing meer nodig**, en juist die maakte in variant C
  een diepe ringsleuf waar support in moest dat niet te verwijderen was. Het
  inwendige is nu gewoon een boring met draad.

Rolverdeling, elk onderdeel doet een ding:

| Functie | Waar |
|---|---|
| Positioneren | de rok landt op de steunring (hard en vlak) |
| Afdichten | O-ring op de flesrand, met 0,3 mm spleet zodat hij kan knijpen |
| Vasthouden | de schroefdraad, die verder nergens tegenaan loopt |

Gemeten aan de Fernandes-fles: steunring 33,07 mm, flesrand tot bovenkant
steunring 14,00 mm. Beide staan bovenin het script.

Nagerekend: zittingvlak van 28,8 tot 38,3 mm, dus contact op de ring over een
ring van ruim 2 mm breed; ruimte over de schroefdraad 28,8 mm (draad is 27,43);
draadruggen op 25,9 mm en netjes doorlopend rond de omtrek; alle steile
overhangen liggen buiten de boring.

**Printen: Gardena-kant op het bed, rok naar boven open.** De draad zit dan aan
de binnenkant met de overhang naar beneden onder circa 50 graden, en dat print
zonder support. Geen holte waar je niet bij kunt. 0,15 mm laagjes, PETG.

**Controle**: hij hoort te STOPPEN op de steunring, met een spleetje van 0,3 mm
tussen dop en flesrand dat de O-ring vult. Loopt hij door tot op de rand, dan is
`RING_AFST` te groot; stopt hij te vroeg, dan te klein. Meet en corrigeer.

## 19. Klemmende schuifrand (testneus en recovery-romp)

Bij de eerste pasproef viel de testneus er gewoon af zodra je de fles omdraaide.
Oorzaak: de fles is bij de BODEM smaller dan de 88,5 mm van de brede band, en
daar schuiven neus en romp overheen. Een vaste maat werkt daar dus niet.

Oplossing: dezelfde als bij de vinnen, namelijk klemmen in plaats van passen.

- vier zaagsneden van 5 mm in de schuifrand, zodat er vier lippen ontstaan
- een groef rondom voor een tiewrap
- klembereik ongeveer 6,4 mm in diameter (van 89,5 tot circa 83 mm)

Daarmee hoeft de exacte flesdiameter op die hoogte niet bekend te zijn. Schuif
het onderdeel op tot tegen het tussenschot, tiewrap in de groef, aantrekken tot
het niet meer draait.

Twee dingen die uit de controle kwamen en die in het ontwerp zitten:

- **Verdikte band onder de tiewrap-groef, bij allebei.** De wand is 1,6 mm
  (romp) en 2,0 mm (testneus); een groef van 1,3 mm diep zou daar 0,3 en 0,7 mm
  van overlaten en bij het aantrekken scheuren. Met de band blijft er 1,75 mm
  respectievelijk 2,15 mm over.
- **De sleuven van de recovery-romp staan 45 graden gedraaid**, zodat ze niet in
  lijn liggen met de deuropening.

De losse ontluchtingsgaten in de schuifrand van de testneus zijn vervallen: de
zaagsneden ontluchten al.

Wordt de fles later opgemeten (omtrek op 1 en 4 cm vanaf de bodem), dan kan
`FLES_SPEL` krapper en wordt de tiewrap een borging in plaats van de hoofdklem.

## 20. Printhoogte: kamer teruggebracht naar 85 mm

De romp was 271 mm hoog en past daarmee niet op een Bambu X1 (256 mm bouwhoogte).
In plaats van hem te splitsen is de parachutekamer teruggebracht van 110 naar
85 mm. Dat scheelt 24 mm en de romp is nu 246,8 mm: ruim 9 mm speling.

Splitsen met een insteekverbinding was het alternatief, maar dat introduceert een
naad precies op de plek waar de parachuteklap aangrijpt. Een kortere kamer is
eenvoudiger en sterker.

Past de parachute nog? De kamer is 85 x 89,5 mm, oftewel 535 cm3. Een opgevouwen
nylon chute van 60 cm is ruwweg 300 tot 400 cm3, dus dat past met ruimte over.
De deuropening (58 x 78 mm) is niet gewijzigd.

Heb je een printer met meer hoogte, dan kun je `KAMER_H` bovenin het script weer
op 110 zetten.

## 21. De punt op de recovery-romp (VERVALLEN, zie 22)

Bovenop komt `PWS_Waterraket_Neuskegel_Tip.stl`, het ogief van 119 mm dat ook op
de oude neuskegel paste. Die punt heeft ZELF een insteekrand aan de onderkant.

Bij een controle bleek de romp daar ook een uitstekende rand te hebben, en twee
uitstekende randen passen niet in elkaar: ze botsten over ruim 5 cm3. De romp is
bovenaan nu een gladde boring van 89,5 mm waar de punt met zijn eigen rand van
88,95 mm in schuift, met 0,55 mm speling.

Totale hoogte romp plus punt: 352 mm, waarvan 50 mm over de fles valt.

De punt hoeft niet los te kunnen: de parachute gaat door de zijdeur naar buiten.
Je kunt hem dus vastzetten met een druppel lijm of met twee kleine zelftappers
door de rompwand in de insteekrand. Wil je schroefgaten in het model, dan zijn
die zo toe te voegen.

## 22. Verwisselbare schroefneus en los schotje

De neus wordt in de romp GESCHROEFD, zodat je verschillende neusvormen kunt
proberen. Daarmee wordt neusvorm een onderzoeksvariabele in plaats van een vaste
keuze.

### De draad

Grof en meergangs: spoed 5 mm, drie gangen, 12 mm lang. Een kwartslag pakt al,
een halve slag zit hij vast. Fijne geprinte draad loopt snel vast door
laaglijnen; deze niet. Kern 87,2 mm, rug 88,8 mm, boring van de romp 89,5 mm.

Nagerekend met de neus daadwerkelijk ingedraaid (dus draaien en tegelijk zakken
langs de schroeflijn): resterende overlap 0,19 cm3, en dat is de meetstap.

### Drie neusvormen

| Bestand | Vorm | Hoogte | Massa |
|---|---|---|---|
| `PWS_Waterraket_Neus_Ogief.stl` | klassiek raketprofiel | 133 mm | ~34 g |
| `PWS_Waterraket_Neus_Kegel.stl` | rechte kegel | 133 mm | ~23 g |
| `PWS_Waterraket_Neus_Elliptisch.stl` | stomp en kort | 103 mm | ~26 g |

Let op bij het vergelijken: de massa verschilt, en massa in de neus beinvloedt de
stabiliteit en de hoogte. Wil je zuiver de VORM meten, voeg dan ballast toe zodat
alle drie even zwaar zijn, en noteer dat.

### Los schotje (belangrijk)

De elektronicaruimte zat tussen twee dichte vloeren, waardoor je de houder er
niet in kon krijgen. De kamervloer is nu een LOS schotje
(`PWS_Waterraket_Recovery_Schot.stl`, 89,1 mm, rust op een richel, 0,4 mm
speling) met twee koordgaten en een doorvoer voor de servodraad.

Volgorde bij het opbouwen: neus eraf, schotje eruit, houder op de rails schuiven,
schotje terug, parachute erin, neus erop.

### Wat er nog meer veranderde

Door de kamer van 110 naar 85 mm te brengen paste de deur niet meer: die was
78 mm hoog en begon 12 mm boven de kamervloer, samen 90 mm. De deuropening stak
daardoor boven de rompbuis uit. De deur is nu 58 x 56 mm en begint 8 mm boven de
vloer. De romp is 231,8 mm, ruim binnen de 256 mm van een X1.

## 23. Nozzle als opzetstuk over de originele dop (voorkeursroute)

Ook de steunring-variant (hoofdstuk 18E) kregen we in de praktijk niet recht op
de fles. De gemene deler bleef: er zat geprinte schroefdraad in.

Deze versie heeft helemaal geen geprinte draad meer:

1. Je draait een ORIGINELE dop op de fles. Spuitgegoten, dus haaks, en hij dicht
   af met zijn eigen liner.
2. In die dop boor je een gat van 10 mm.
3. Het geprinte opzetstuk valt OVER de dop en haakt met vier vingers onder de
   steunring. Daarmee kan de druk het er niet afduwen.
4. Onderaan zit de Gardena-steel voor de launcher.

Uitlijning komt van de steunring (33,07 mm, spuitgegoten en rond). Nagemeten:
rok binnen 33,70 mm (0,63 mm speling), lip binnen 31,47 mm (grijpt 0,8 mm per
zijde onder de ring), tiewrap-groef aanwezig, sleuven open.

**Afdichting op twee plekken**: de originele dop op de flesrand, en een O-ring
(16 x 2 mm) tussen het opzetstuk en de bovenkant van de dop. De druk duwt het
opzetstuk tegen de vingers, en die trekken de O-ring juist aan. Dat is gunstig:
meer druk is betere afdichting.

**Montage**: gat boren, O-ring plaatsen, dop op de fles, opzetstuk eroverheen
drukken tot de vingers klikken, tiewrap in de groef zodat ze niet kunnen
openwijken.

**Twee maten nameten** (bovenin het script):
- `DOP_HOOGTE`, van de bovenkant van de dop tot de bovenkant van de steunring;
  staat op 16,0 mm. Reken op de 14,0 mm van flesrand tot ring plus de dikte van
  de dopbovenkant.
- `RING_DIK`, de dikte van de steunring; staat op 1,8 mm.

Klopt de eerste niet, dan klikt hij niet of zit hij los.

Maten 4 tot en met 9 mm; 9 blijft de bovengrens door de Gardena-steel.

Printen: Gardena-kant op het bed, geen supports, PETG, 0,2 mm laagjes.

## 24. Nozzle om op de dop te LIJMEN

Variant op hoofdstuk 23, maar dan vastgelijmd in plaats van vastgeklikt. Geen
vingers, geen tiewrap, geen maat die precies moet kloppen.

Opbouw: Gardena-steel, een plaat op de bovenkant van de dop, en een rok die
9,5 mm over de dop valt. Die rok is het lijmvlak, circa 895 mm2.

**Belangrijk: lijm hecht slecht op doppen.** Flesdoppen zijn van HDPE of PP, en
die hebben een lage oppervlakte-energie. Gewone tweecomponentenlijm pakt daar
nauwelijks op aan, hoe goed je ook schuurt. Opties van sterk naar zwak:

1. Lijm die voor polyolefinen gemaakt is: 3M DP8010, of secondelijm met een
   primer zoals Loctite 770.
2. Gewone epoxy, maar dan schuren EN kort vlammen met een aansteker, en direct
   lijmen.
3. Gewone epoxy op een onbehandelde dop: dit laat los.

Daarom zitten er **drie schroefgaten** van 2,2 mm in de rok als achtervang.
Die gaan alleen door de rokwand, niet dwars door het hele deel: een doorlopend
gat zou binnenin tegen de fleshals komen. Zet er na het lijmen drie korte
zelftappers in, de dopwand in.

Rekensom ter geruststelling: bij 7 bar en een afdichting op 16 mm staat er circa
14 kg kracht op het deel. Over 895 mm2 lijmvlak is dat 0,13 N/mm2. Weinig, maar
op onbehandeld PP haal je zelfs dat niet.

Er zitten drie lijmgroeven in de rok, zodat de lijm ergens in kan blijven staan
in plaats van er bij het opdrukken helemaal uit te worden geperst.

**Montage**: 10 mm boren, dop ruw schuren en ontvetten, O-ring 16 x 2 mm in de
groef, lijmen, 24 uur uitharden (niet de snelle vijfminutenvariant), dan de drie
zelftappers, en pas daarna op de fles draaien.

**Nameten**: `DOP_D` (30,0) en `DOP_H` (11,5) bovenin het script. Te ruim is geen
probleem, want de lijm vult dat op; te krap gaat er niet overheen.

## 25. Drie printfouten hersteld (recovery-romp, deur, neus)

Uit de eerste print van de recovery-set kwamen drie problemen. Alle drie zaten
in het model, niet in de printer.

**De neus schroefde er niet in.** 0,35 mm speling is te weinig voor een geprinte
draad van 89 mm doorsnede: een PETG-binnendraad krimpt naar binnen en de
buitenlaag van de neus komt dikker uit dan getekend. De draad is nu 2,2 mm diep
(was 1,5) met 0,7 mm speling, en de romp heeft bovenaan een aanloopschuinte zodat
de neus makkelijk aanzet. Nagerekend met de neus ingedraaid langs de schroeflijn.

**De deurtabs kwamen los.** Het scharnieroog hing onder de onderrand van het
paneel en de grendellip raakte de buitenflens net niet. In het model waren het
dus losse stukjes, en zo printte de slicer ze ook. Dat had de controle moeten
vangen; die keek alleen naar de romp en niet naar de deur. Nu: oog en lip steken
in het paneel, de deur is aantoonbaar een geheel.

**De rails printten slecht.** Het waren vrije ribben van 82 mm hoog en 3 mm dik
die alleen op de bodem stonden. Die wiebelen bij het printen. Ze lopen nu door
tot in de rompwand en zijn daarmee wandribben.

De controle checkt voortaan bij alle delen of ze uit een stuk bestaan.

## 26. Tweede printronde: gat in de neus, gat in de draad

Twee fouten uit de tweede print, allebei in het model.

**Gat in de top van de neus.** Het ogiefprofiel was bij de top vrijwel vlak (op
1 mm onder de punt nog 11 mm straal). De holte binnenin eindigde daardoor in een
plat plafond van bijna 2 cm, en dat kan een printer alleen met support maken. Dat
support zit in een gesloten holte: bij het verwijderen prik je er doorheen.

Nu: een echt tangent-ogief (cirkelboog, rakend in de romp, eindigend in een
punt, afgeplat op 2,5 mm straal). De holte volgt de buitenvorm met vaste wand,
maar het plafond mag nergens vlakker worden dan 52 graden en de top is massief.
Het script zoekt per vorm het hoogste punt waar de holte veilig kan sluiten.
Gecontroleerd: top dicht, een geheel, binnenin alleen een kleine brug van 8 mm.

**Gat in de schroefdraad van de romp.** Met de kamer op 85 mm paste de stapel
niet: deur (56) plus servoplank en servovak (34) plus draad (16) is 106 mm. Het
servovak sneed dwars door de draadzone en de bovenrand. Twee wijzigingen:
de kamer is weer 100 mm (romp 246,8 mm, past op een X1), en de servo ligt nu
plat op een plankje boven de deur met zijn as tangentieel. Het lichaam is dan
maar 12,6 mm hoog en het vak blijft binnen straal 43, los van de wand.

De grendellip zit daardoor niet meer in het midden maar op y=16, aan de kant
waar de servo-as uitsteekt, met het gat in de lip evenwijdig aan die as.

**Nog twee kleinere dingen die de strengere controle vond:**
- het scharnierpengat was 200 mm lang en priemde ook door de wand aan de
  overkant; het is nu 16 mm, alleen door de blokjes en de wand aan de deurkant
- de romp werd na het wegschrijven lek (float32-afronding rond het pengat); de
  export heeft nu dezelfde opschoonstap als de andere delen, met controle na
  het inlezen

**Controles die voortaan bij elke run draaien:** elk deel een geheel; wand in de
draadzone rondom heel op 72 hoeken; servovak raakt de wand niet; deur valt vrij
in het kozijn; houder past; neus draait er langs de schroeflijn in; top van elke
neus massief; geen plat plafond in de holte.

## 27. Compact: van 302 naar 193 mm boven de fles

De hele constructie was groter dan de fles zelf. Drie ingrepen:

| Deel | Was | Nu | Hoe |
|---|---|---|---|
| Elektronicaruimte | 92 mm | 26 mm | bord, accu en sensor liggen PLAT in een rond bakje (`PWS_Waterraket_Tray.stl`, 13 mm) in plaats van rechtop in een houder |
| Parachutekamer | 100 mm | 80 mm | servo zit NAAST de deur op dezelfde hoogte, niet meer erboven |
| Neus | 105 mm | 80 mm | korter ogief; bij deze snelheden niet meetbaar |

Romp 160,8 mm (was 246,8), ogief 96,7 mm incl. draad (was 121). Boven de fles
nu 193 mm. Massa: romp ~58 g, tray ~45 g (slicer-infill maakt dat minder), deur
5 g, neus 19 g.

**De tray** vervangt de houder. Het scherm kijkt omhoog: neus eraf en je ziet
het. Alle vakken liggen binnen straal 42 (rand op 42,5), met vingergaten in de
bodem om de onderdelen eruit te tillen en twee kabelgoten naar het bord. Hij
ligt los op de vloer van de elektronicaruimte; het schotje erboven houdt hem op
zijn plek. De statische poorten zitten nu op 8 mm boven die vloer, op sensorhoogte.
De oude houder staat in het archief.

**De servo** ligt tangentieel op een plankje tegen de wand, op 53 graden naast
de deur, as naar de deur. De hoorn draait in het radiaal-verticale vlak vlak
naast de deurrand en pakt een lip aan de BINNENKANT van de deur (y=23, binnen
het kozijnvenster zodat hij bij het openen niet achter de rand blijft haken).

**Het scharnier bleek al vanaf het begin fout.** De blokjes stonden op y=21 waar
de ronde wand al naar binnen loopt, en staken daardoor 1,8 mm buiten de romp.
Belangrijker: het pengat liep radiaal, terwijl een scharnieras tangentieel moet
lopen door beide blokjes en het deuroog. Dat scharnier had nooit kunnen draaien.
Nu: as langs y op x=36, blokjes met de boring afgesneden zodat ze in de wand
versmelten, oog dieper naar binnen. Gecontroleerd: as over 60 mm vrij, materiaal
eromheen in beide blokjes en het oog, niets buiten de romp. Het stukje filament
steek je van buitenaf door de wand in.

## 28. Laatste controle voor het printen

Twee dingen gevonden bij een laatste ronde:

- **Het schotje botste met het scharnier.** Het schotje ligt op de richel
  (vloer tot vloer+3 mm); de scharnierblokjes begonnen 1 mm onder de vloer en
  het deuroog erboven. Dat zat erin sinds het schotje bestaat, maar schotje en
  deur waren nooit samen gecontroleerd. De deur begint nu 14 mm boven de vloer
  (was 8), de kamer is 86 mm, de romp 166,8 mm. Overlap schot-romp en
  schot-deur nu 0.
- **Het servoplankje zweefde.** Een horizontaal plateau van 27 mm vrij uit de
  wand print niet. Er zit nu een 45-gradenwig onder, in de wand geklemd.

De controle draait nu twaalf punten: alle delen een geheel; deur in kozijn;
schotje op de richel en vrij van de deur; tray in de romp en onder het schotje;
draadzone rondom heel; niets buiten de romp; scharnieras vrij door blokjes,
oog en beide wanden; platte plafonds binnenin verklaard; neus draait erin.

**Slicer-instelling voor de romp**: supports AAN, maar "alleen vanaf het
printbed" (Bambu: support on build plate only). De enige plek die support nodig
heeft is de vloer boven de fles: die overspant de volle boring en wordt van
onderaf geprint. Dat support staat in de open schuifrand en breekt er zo uit.
Binnenin de romp komt dan nergens support, en dat is precies de bedoeling.

Boven de fles nu 199 mm.

## 29. Waarom de neus er nooit in draaide: een rekenfout, geen printprobleem

De neus paste bij geen enkele print, ook niet met meer speling. Een proefstuk
(draadring plus drie neusstompjes met 0,7, 0,9 en 1,1 mm speling) legde het
bloot: de overlap werd GROTER bij meer speling. Dat kan alleen bij een fout in
de geometrie.

Die fout: de kern van de neusdraad lag op straal `R_IN - diepte + speling`, dus
BOVEN de ruggen van de romp (die tot `R_IN - diepte` naar binnen steken). De
rompruggen botsten daardoor over de hele lengte 0,7 mm in de neuskern. Elke
neus die tot nu toe geprint is, kon er op papier al niet in. De eerdere
controle gaf 0,37 cm3 overlap, en dat is ten onrechte als "aanrakende flanken"
weggeschreven in plaats van als botsing.

Correct: kern op `R_IN - diepte - speling`. Na de correctie: overlap 0,026 cm3
bij 0,7 mm, 0,007 bij 0,9 en 0,000 bij 1,1, netjes aflopend. De neuzen staan nu
op 0,9 mm.

**Proefstukken** staan in `genereer_test_draad.py`: `Test_Draadring` (de
bovenste 18 mm van de romp) en `Test_Neusstomp_07/09/11`. Print bij twijfel
eerst de ring (11 g) met een neus; past die, dan past de romp. Dat scheelt een
romp van 64 g per poging.

De romp hoeft NIET opnieuw: de rompdraad was goed, de fout zat alleen in de
neus.

## 30. Deur verbreed naar 70 mm

Na het compacter maken was de deur 54 x 50 mm geworden, te krap voor een
parachute van 60 cm. Nu 70 x 50 mm (deuropening), kozijnvenster 65 x 45 mm.

De servo is meegeschoven om de omtrek: hij staat nu op de deurhalfhoek plus 21
graden, dus altijd net voorbij de deurrand, ook als `DEUR_B` later verandert.
De grendellip zit op `DEUR_B/2 - 4`, binnen het kozijnvenster.

Gecontroleerd na de wijziging: deur een geheel en vrij in het kozijn, schotje
en tray vrij, draadzone heel, niets buiten de romp, scharnieras vrij, wand naast
de deur (buiten 51 graden) rondom heel, neus draait erin.

## 31. Schotje en tray in helften: wat er niet door de opening paste

Het schotje kreeg je er met geen mogelijkheid in. Terecht: het was 89 mm rond,
de schroefdraad laat 85 mm door en het deurvenster 65. Het paste in geen enkele
opening. En bij het nalopen bleek de tray (ook 89 mm) hetzelfde probleem te
hebben, plus een tweede: het servoplankje steekt 27 mm de boring in, dus zelfs
een kleinere ronde schijf komt er niet langs.

De regel die voortaan bij elke run gecontroleerd wordt: **elk los deel moet door
een opening van de romp passen.**

Oplossing voor allebei: twee helften.

**Schotje** (`Recovery_Schot_A/B`): twee halve schijven van 89 mm met een
overlapnaad van 8 mm in het midden. Elke helft is 48 mm breed en gaat zo door
de draad. Een halve schijf ligt stabiel op de richel: haar zwaartepunt ligt op
19 mm van de rechte kant, ruim binnen de steunboog. Koordgat in elke helft,
servodraadgat in A.

**Tray** (`Tray_A/B`): 82 mm, zodat hij ook plat door het richelgat (83,5) kan.
De naad ligt niet in het midden: het bord (41 x 33) past niet in een halve
schijf omdat zijn hoeken buiten de boog steken, dus het ligt over het midden
heen in de grote helft A (43,5 mm breed). Helft B (38,5 mm) draagt accu (een
kwartslag gedraaid) en sensor. Alle vakken hebben minstens 1,5 mm wand tot de
naad en 1,8 mm tot de rand.

**Inbrengen**: neus eraf. Eerst tray B, aan de kant tegenover het servoplankje
laten zakken en over de bayvloer naar zijn plek schuiven. Dan tray A, zelfde
kant, blijft daar liggen. Dan de schothelften op de richel, A met de lip boven.
Daarna parachute en neus. De oude ronde tray en het ronde schotje staan in het
archief.

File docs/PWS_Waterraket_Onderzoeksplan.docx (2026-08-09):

PROFIELWERKSTUK – NATUURKUNDE

De Waterraket

Welke factoren bepalen de prestatie van een waterraket?

Onderzoeksplan – theoretisch kader, testplan & uitvoering

Vak: Natuurkunde · Niveau: vwo 5

Type document: onderzoeksplan (fase 1)

# Inhoudsopgave

# 1. Inleiding en aanleiding

Een waterraket is een verbluffend eenvoudig systeem met verrassend rijke natuurkunde. Een PET-fles wordt gedeeltelijk met water gevuld, daarna wordt er via een ventiel lucht in geperst. Zodra de fles wordt losgelaten, perst de samengeperste lucht het water met hoge snelheid door de opening naar buiten. Volgens de derde wet van Newton ondervindt de fles daardoor een even grote, tegengestelde kracht: de raket schiet omhoog. Zonder verbranding, zonder gevaarlijke brandstof – puur lucht, water en druk.

Juist die eenvoud maakt de waterraket geschikt voor een degelijk natuurkundig onderzoek. Alle relevante grootheden (vulhoeveelheid, druk, openingsdiameter, massa, vorm) zijn zelf in te stellen en te variëren, en de prestatie is goed meetbaar. Tegelijk is het systeem complex genoeg om echte trade-offs te laten zien: meer water betekent meer terugstootmassa, maar ook meer gewicht; een kleinere opening verlengt de stuwfase, maar verlaagt het massadebiet. Er bestaat dus een optimum, en dat optimum opsporen is precies wat een onderzoek interessant maakt.

Dit document is het onderzoeksplan: het legt de onderzoeksvraag vast, bouwt het theoretisch kader op, benoemt welke factoren we onderzoeken (en welke verwachte uitkomsten de theorie voorspelt), bepaalt wat haalbaar is, beschrijft de raketmodellen en de testopstelling, en sluit af met een stappenplan en een complete materiaallijst (BOM).

# 2. Onderzoeksvraag en hypothesen

## 2.1 Hoofdvraag

Welke factoren beïnvloeden de prestatie van een waterraket, en welke instellingen leveren – voor een gegeven flesvolume – de grootste apogeumhoogte op?

Met “prestatie” bedoelen we in dit onderzoek primair de maximale hoogte (het apogeum). Als secundaire prestatiematen meten we waar mogelijk ook de vluchttijd en de stabiliteit (recht of tollend).

## 2.2 Deelvragen

- Bij welke watervulfractie bereikt de raket de grootste hoogte?
- Hoe hangt de hoogte af van de begindruk (binnen het veilige bereik)?
- Welk effect heeft de openings-/nozzlediameter op stuwkracht, stuwduur en hoogte?
- Hoe beïnvloeden totale massa en de positie van het zwaartepunt (neusgewicht) de prestatie en de stabiliteit?
- Hoe beïnvloeden het vinoppervlak, het aantal vinnen en de vorm van de neuskegel de stabiliteit en de luchtweerstand?
- Wat is het effect van de lanceerhoek op hoogte versus horizontaal bereik?
- Hoe verandert de prestatie met het flesvolume en met gekoppelde flessen (groter luchtvolume)?

## 2.3 Hypothesen (te toetsen)

- H1 – Er bestaat een optimale watervulfractie rond ongeveer een derde van het flesvolume; zowel te weinig als te veel water verlaagt de hoogte.
- H2 – De hoogte neemt toe met de begindruk, bij benadering ongeveer evenredig met de druk, zolang het systeem niet faalt.
- H3 – Een kleinere opening verlengt de stuwfase maar verlaagt de piekstuwkracht; er is een optimum tussen “korte harde duw” en “lange zachte duw”.
- H4 – De raket vliegt alleen stabiel als het zwaartepunt vóór het drukpunt ligt; extra neusgewicht verbetert de stabiliteit maar voegt gewicht toe en verlaagt boven een grens de hoogte.
- H5 – Te kleine vinnen geven instabiliteit (tollen); te grote vinnen geven extra luchtweerstand. Er bestaat een optimaal vinoppervlak.

# 3. Theoretisch kader

Hieronder bouwen we de theorie stapsgewijs op: van de aandrijving (waarom de raket omhoog gaat), via de drie vluchtfasen, naar de aerodynamica en de stabiliteit. De formules zijn bewust op vwo-niveau gehouden, maar wel volledig genoeg om kwantitatieve voorspellingen te doen.

## 3.1 Aandrijving: stuwkracht en impulsbehoud

De waterraket werkt op de wet van behoud van impuls (Newton 2 en 3). Per tijdseenheid wordt een massa water met een snelheid naar achteren uitgestoten; de bijbehorende impulsverandering levert een voorwaartse stuwkracht. De stuwkracht is gelijk aan het massadebiet maal de uitstroomsnelheid:

F_stuw = (dm/dt) · v_uit

Het massadebiet door de opening met oppervlakte A bedraagt dm/dt = ρ_water · A · v_uit, met ρ_water ≈ 1000 kg/m³. De uitstroomsnelheid volgt uit de wet van Bernoulli (vereenvoudigd tot Torricelli): de overdruk in de fles wordt omgezet in kinetische energie van het water:

½ · ρ_water · v_uit² = Δp ⇒ v_uit = √(2 · Δp / ρ_water)

Hierin is Δp = p_binnen − p_buiten de overdruk. Combineren we deze uitdrukkingen, dan ontstaat een opvallend simpel en krachtig resultaat:

F_stuw = ρ_water · A · v_uit² = 2 · A · Δp

Conclusie uit de theorie: de stuwkracht is recht evenredig met de openingsoppervlakte A én met de overdruk Δp. Een grotere opening of een hogere druk geeft dus meer kracht. Maar een grotere opening leegt de fles ook sneller (kortere stuwduur), en daar zit de trade-off die we experimenteel onderzoeken.

## 3.2 De lucht als energiebron

De energie zit niet in het water maar in de samengeperste lucht erboven. Tijdens de stuwfase zet die lucht uit en duwt het water naar buiten. Als benadering geldt voor het gas de gaswet. Bij langzame processen is dat ongeveer isotherm (p · V = constant); bij de snelle uitstroom van een waterraket is het eerder adiabatisch (p · V^γ = constant, met γ ≈ 1,4), waarbij de lucht afkoelt terwijl ze expandeert. De maximaal beschikbare energie neemt toe met zowel de begindruk als het luchtvolume – vandaar dat een groter luchtvolume (minder water, of een grotere/gekoppelde fles) meer “brandstof” betekent.

Belangrijk inzicht: als de fles volledig met water wordt gevuld, is er geen lucht om samen te persen – water is bij deze drukken vrijwel onsamendrukbaar – en kan er nauwelijks energie worden opgeslagen. Er moet dus altijd een luchtkussen zijn. Dat verklaart fysisch waarom een optimale vulfractie bestaat.

## 3.3 De drie vluchtfasen

- Stuwfase (waterfase): zolang er water is, levert de uitstroom een grote stuwkracht. Deze fase duurt kort (orde 0,1–0,3 s) maar geeft een enorme versnelling (tientallen tot honderden m/s²). De massa van de raket neemt snel af, waardoor de versnelling tijdens deze fase nog verder oploopt (F = m·a met dalende m).
- Luchtstuwfase (kort en optioneel): als bij het legen nog overdruk resteert, blaast lucht naar buiten en levert nog een kleine extra duw. De bijdrage aan de tophoogte is klein en wordt vaak verwaarloosd.
- Coast- of ballistische fase: na de stuw vliegt de raket vrij omhoog, alleen afgeremd door de zwaartekracht en de luchtweerstand. De raket vertraagt tot de snelheid nul is: dat punt is het apogeum (de maximale hoogte die we meten).
- Daling: daarna valt de raket terug; bij een geavanceerd model met parachute wordt de val afgeremd (recovery).

## 3.4 Aerodynamica: luchtweerstand

Tijdens de vlucht werkt de luchtweerstand tegen de beweging in:

F_weerstand = ½ · ρ_lucht · C_d · A_front · v²

Hierin is ρ_lucht ≈ 1,2 kg/m³, C_d de luchtweerstandscoëfficiënt (afhankelijk van de vorm), A_front het frontale oppervlak en v de snelheid. Omdat de weerstand met het kwadraat van de snelheid groeit, is hij juist vlak na de lancering – bij de hoogste snelheid – het grootst. Een gladde, gestroomlijnde neuskegel verlaagt C_d; uitstekende randen, plakband en grote vinnen verhogen hem.

## 3.5 Stabiliteit: zwaartepunt en drukpunt

Een raket vliegt alleen recht als hij aerodynamisch stabiel is. Twee punten zijn bepalend:

- Het zwaartepunt (Z, center of mass): het balanspunt waarom de raket draait. Te vinden door de raket horizontaal op één vinger te balanceren.
- Het drukpunt (D, center of pressure): het punt waarop de aerodynamische krachten netto aangrijpen. Het ligt daar waar het zijaanzicht-oppervlak vóór en achter even groot is.

Stabiliteitsvoorwaarde: het zwaartepunt moet vóór het drukpunt liggen (dichter bij de neus). Dan ontstaat bij een verstoring een terugdraaiend moment dat de raket weer recht zet – net zoals de veren aan de staart van een pijl die recht houden. Ligt het drukpunt vóór het zwaartepunt, dan versterkt elke verstoring zichzelf en gaat de raket tollen.

De afstand tussen zwaartepunt en drukpunt heet de statische marge. Een vuistregel uit de modelraketterie is een marge van minimaal ongeveer één rompdiameter (“1 kaliber”). Praktische ingrepen: neusgewicht verplaatst het zwaartepunt naar voren (stabieler), grotere of verder naar achteren geplaatste vinnen verplaatsen het drukpunt naar achteren (stabieler). De stabiliteit toetsen we vóór elke lancering met de swing-test: bind een touw om de romp ter hoogte van het zwaartepunt en zwaai de raket rond; wijst de neus in de draairichting, dan is de raket stabiel.

## 3.6 Samenvatting van de theorie als voorspelling

Uit het bovenstaande volgt het verwachte gedrag dat we toetsen: stuwkracht ∝ A·Δp; een optimale vulfractie rond ⅓ (luchtvolume als energiebuffer versus water als terugstootmassa); hoogte stijgt met druk; een nozzle-optimum tussen kracht en stuwduur; en stabiliteit die staat of valt met de ligging van zwaartepunt ten opzichte van drukpunt. Deze voorspellingen vormen de “theoretische resultaten” waaraan we de metingen straks spiegelen.

# 4. Te onderzoeken factoren en verwachte resultaten

De onderstaande tabel vat de onafhankelijke variabelen samen die we systematisch variëren, met per factor het theoretisch verwachte effect en de meetbaarheid. Uitgangspunt: we variëren steeds één factor tegelijk en houden de rest constant (ceteris paribus).

Factor | Bereik (indicatief) | Verwacht effect (theorie) | Meetbaar?
Watervulfractie | 20–60 % van flesvolume | Optimum rond ⅓; te weinig = te weinig terugstootmassa, te veel = te zwaar en te weinig luchtenergie | Goed
Begindruk | 3–7 bar (veilig bereik) | Hoogte stijgt met druk (Δp), ruwweg evenredig; bovengrens door veiligheid | Goed
Nozzle-/openingdiameter | Standaard ~9 mm vs. vernauwd | Kleinere opening: lagere piekkracht, langere stuwduur → optimum | Goed
Totale massa / neusgewicht | +0 tot +150 g klei in neus | Meer massa = lagere versnelling, maar verbetert stabiliteit; optimum | Goed
Vinnen (oppervlak/aantal) | 3 of 4 vinnen, klein–groot | Te klein = tollen; te groot = extra weerstand; optimum | Goed
Neuskegelvorm | Plat vs. afgerond/ogief | Gestroomlijnd verlaagt C_d → hogere top | Redelijk
Lanceerhoek | 70–90° | 90° = max hoogte; lagere hoek = meer bereik, minder hoogte | Goed
Flesvolume / koppeling | 1,0 / 1,5 / 2,0 L; gekoppeld | Groter luchtvolume = meer energie; zwaarder bij meer water | Redelijk

De drie controlevariabelen die we constant houden (en noteren): watertemperatuur, windkracht en lanceerlocatie. Deze beïnvloeden de uitkomst maar zijn geen onderzoeksdoel; we sluiten ze zoveel mogelijk uit door dezelfde dag, windstil weer en dezelfde plek te kiezen.

Drie van deze factoren – nozzlediameter, vinnen en neuskegelvorm – lenen zich uitstekend voor 3D-printen. Daarmee maken we per factor een reeks onderdelen die op één parameter na volledig identiek zijn, wat de metingen veel zuiverder en beter reproduceerbaar maakt. Hoe we dat precies aanpakken, staat in hoofdstuk 7.

# 5. Haalbaarheid: wat wel en wat niet

Een eerlijk onderzoeksplan benoemt zijn grenzen. Hieronder staat wat met een schoolbudget en redelijke veiligheid goed te doen is, en wat we bewust buiten scope houden of als optionele “stretch” markeren.

## 5.1 Goed haalbaar (kern van het onderzoek)

- Variëren van watervulfractie, begindruk, nozzlediameter, massa/neusgewicht, vinnen en lanceerhoek – allemaal eenvoudig in te stellen en te herhalen.
- Hoogte meten met de trigonometrische methode (hoekmeter + bekende afstand). Goedkoop, robuust en nauwkeurig genoeg.
- Stabiliteit beoordelen met de swing-test vooraf en met video achteraf (recht versus tollend).
- Meerdere herhalingen per instelling (n ≥ 3–5) voor een gemiddelde en spreiding.

## 5.2 Lastig of beperkt haalbaar

- Exacte bepaling van de luchtweerstandscoëfficiënt C_d – dit vergt windtunnel of geavanceerde meting; we benaderen het effect kwalitatief (gladder = hoger).
- Interne druk- en snelheidsmeting tijdens de vlucht – vereist sensoren/telemetrie; optioneel met een lichte altimeter, maar niet noodzakelijk.
- Betrouwbare parachute-recovery – mooi maar storingsgevoelig; we behandelen het als optie bij het geavanceerde model, niet als meetdoel.

## 5.3 Buiten scope (bewust niet)

- Meertraps (getrapte) raketten met scheiding tijdens de vlucht – mechanisch complex en risicovol; alleen als theoretische bespreking, niet als bouw-/meetdoel.
- Supersone effecten – niet van toepassing: waterraketten blijven ruim onder de geluidssnelheid.
- Zeer hoge drukken (> 7–8 bar) of niet-frisdrankflessen – om veiligheidsredenen uitgesloten (zie §8.4).

# 6. Raketmodellen

We werken met een reeks van eenvoudig naar geavanceerder, zodat we de testopstelling eerst op een simpel model kunnen kalibreren en daarna gericht kunnen optimaliseren. Alle modellen zijn gebouwd op koolzuurhoudende-frisdrank-PET-flessen, die voor druk zijn ontworpen.

Model | Beschrijving | Doel in het onderzoek | Complexiteit
A – Basis | 1,5 L PET-fles, kale romp, 3–4 kartonnen/plastic vinnen, eenvoudige neuskegel, klei als ballast | Referentie/nulmeting; kalibratie van de meetopstelling | Laag
B – Geoptimaliseerd | Gestroomlijnde, gladde romp (tape strak), getapte/afgeronde neuskegel, nauwkeurig geplaatste vinnen, ingesteld neusgewicht | Hoofdmetingen: optimaliseren van vulfractie, druk, nozzle, vinnen | Midden
C – Gekoppelde flessen | Twee flessen verbonden (bv. nek-aan-nek koppeling) voor groter luchtvolume/drukvat | Effect van groter luchtvolume en massa onderzoeken | Midden-hoog
D – Getrapt (stretch) | Twee trappen met scheiding tijdens vlucht | Alleen theoretisch bespreken; niet bouwen tenzij tijd over | Hoog

Belangrijk: de modellen A, B en C zijn de echte werkpaarden van het onderzoek. Model D nemen we mee als theoretische verdieping, zodat het verslag compleet is zonder dat we onnodig risico of complexiteit toevoegen.

Model B krijgt waar mogelijk 3D-geprinte onderdelen (nozzle, verwisselbare vinnen, neuskegel), juist omdat dat de parametrische metingen mogelijk maakt. De volledige uitwerking en de gebruikte modelbestanden staan in hoofdstuk 7.

# 7. 3D-geprinte onderdelen en parametrische varianten

De beschikbaarheid van een 3D-printer is voor dit onderzoek meer dan een handigheid: het is een methodologisch voordeel. De winst zit in parametrische reproduceerbaarheid – we kunnen onderdelen maken die op precies één maat na identiek zijn. Daarmee verandert een ruwe vergelijking (“klein versus groot”) in een echte meetreeks waaruit een optimumcurve volgt, en halen we belangrijke storende variabelen (handwerk, scheve plaatsing, verschillen tussen exemplaren) uit de data.

## 7.1 Geprinte nozzles – de sterkste meetreeks

De openingsdiameter is de factor die het meest profiteert. In plaats van een standaardopening met een vernauwde variant printen we een serie nozzles met identieke geometrie maar oplopende opening (bijvoorbeeld 4, 6, 8 en 10 mm) en meten we per diameter zowel de hoogte als de stuwduur. Bestaande, vrij beschikbare ontwerpen maken dit mogelijk: het Raketfued-systeem biedt nozzles met instelbare opening tussen 4 en 10 mm die op standaard tuinslangkoppelingen passen, en US Water Rockets en diverse makers op Thingiverse delen Gardena-compatibele nozzles. Bronnen en bestanden staan in hoofdstuk 12.

Veiligheid voorop: de nozzle staat onder volle druk en is daarmee het kritische onderdeel. Geprinte (FDM) onderdelen zijn anisotroop – ze kunnen langs de printlagen scheuren – dus een drukvoerende print moet altijd eerst worden getest door de raket volledig met water te vullen en achter een afscherming op druk te brengen (water is vrijwel onsamendrukbaar, dus bij een breuk komt weinig energie vrij). Print drukdelen op circa 100 % vulling met veel wanden, of – nog betrouwbaarder – gebruik een gekochte Gardena-koppeling voor de eigenlijke afdichting en print alleen het flesdraad-adapterstuk. Reken voor de afdichting op een passende O-ring (veel ontwerpen vragen een Viton 111 O-ring) en een tuinslangring.

## 7.2 Verwisselbare vinnen – confound eruit

Handgesneden vinnen verschillen onvermijdelijk per exemplaar en zitten zelden perfect recht; dat is precies het soort ruis dat een meting vertroebelt. Met een geprinte vinhouder of een verwisselbaar “fin can”-systeem wisselen we hele vinsets op hetzelfde rakethuis, zonder lijm. Daarmee meten we het effect van vinoppervlak, aantal (3 vs. 4) en pijlvorm terwijl al het andere identiek blijft. Het commerciële Estes Scorpio 3D demonstreert dit principe met een twist-lock fin can en uitwisselbare vinvormen; voor waterraketten bieden US Water Rockets zelf-uitlijnende vinbrackets, en op Printables staan complete fles-vinsets. Wie toch losse vinnen lijmt, gebruikt een geprinte uitlijnmal voor een exacte 120°- of 90°-verdeling.

## 7.3 Neuskegel en ballast

Voor de neuskegelvorm printen we varianten (plat, halfrond, conisch, ogief) met gelijke massa, zodat alleen de luchtweerstandscoëfficiënt verandert. Een holte in de neuskegel met een schroefdop laat ons bovendien exact ballastgewicht toevoegen, wat de zwaartepunt-/stabiliteitsproeven nauwkeurig en herhaalbaar maakt. Let op: een harde geprinte neuskegel komt als een “lawn dart” naar beneden – print hem in een flexibel materiaal of combineer hem met een recovery-systeem. Als we de optionele onboard-elektronica gebruiken, dient de neuskegel tegelijk als payloadcompartiment; de uitwerking en de bijbehorende fleskeuze staan in hoofdstuk 12.

## 7.4 Recovery (optioneel)

Een geprint parachute-/recoverysysteem (bijvoorbeeld een neuskegel die bij het apogeum loskomt, of een tijd-/servogestuurd mechanisme) is mooi maar storingsgevoelig en geen meetdoel. We behandelen het als optionele uitbreiding bij model B/C, niet als onderdeel van de kernmetingen.

## 7.5 Print- en materiaaladvies

- Materiaal: PLA of PETG voldoet; PETG is taaier voor drukdelen. Voor neuskegels is een flexibel filament veiliger bij de landing.
- Instellingen drukdelen (nozzle/koppeling): fijne laaghoogte, veel perimeters en hoge vulling (richting 100 %).
- Instellingen niet-drukdelen (vinnen/mal/neuskegel): standaard laaghoogte, matige vulling volstaat.
- Test elk drukvoerend onderdeel vol water achter een afscherming vóór de eerste echte vlucht.

## 7.6 Concrete modelbestanden

De onderstaande, online vrij beschikbare ontwerpen zijn bruikbaar als basis of inspiratie. De volledige URL’s staan in de bronnenlijst (hoofdstuk 12).

Onderdeel | Bron / maker | Wat het is | Platform
Nozzles (instelbaar) | Raketfued | Modulaire nozzles, opening 4–10 mm, Gardena-compatibel; ook neuskegels en recovery | raketfuedrockets.com
Gardena-nozzle | US Water Rockets | Klassieke schroef-op-fles nozzle die in een Gardena-release klikt | Thingiverse 781367
Nozzle (easy print) | Kendalf | Eenvoudiger te printen frisdrakfles-nozzle voor Gardena-koppeling | Thingiverse 7174682
Complete set | sage | Neuskegel + nozzle + vinnen; vraagt Viton 111 O-ring + tuinslangring | Printables 976435
Vinnen + neuskegel | HAL_9000 | 2 L-set met losvallende neuskegel voor parachute; meerdere vinmaten | Printables 208609
Vin-uitlijnmal | fl_mike / Steamboat Ed | Mal voor exacte 3- en 4-vin plaatsing bij het lijmen | Printables 214186 / 194071
Zelf-uitlijnende vinbrackets | US Water Rockets | Geprinte brackets voor reproduceerbare vinmontage | uswaterrockets.com
Verwisselbare fin can | Estes Scorpio 3D | Twist-lock fin can met uitwisselbare vinvormen (modelraket, concept bruikbaar) | estesrockets.com
Launcher + nozzle | mockfrog | Complete lanceerinstallatie rond een Gardena-nozzle | Thingiverse 3127479

# 8. Testopstelling

## 8.1 Lanceerinstallatie

We bouwen een drukvaste lanceerinstallatie die de fles ondersteboven vasthoudt, het luchtkanaal afsluit, en op afstand vanaf een touw kan worden ontgrendeld. Een beproefd, goedkoop en betrouwbaar ontwerp is de kabelbinder-ontgrendeling (“Clark cable tie release”) op een PVC-lanceerbuis, eventueel gecombineerd met een Gardena-snelkoppeling als afdichting.

- Lanceerbuis: PVC-buis (ø ~22 mm) die in de flesopening past, met een O-ring voor de luchtdichte afsluiting.
- Vergrendeling: een ring van zware kabelbinders grijpt onder de flesrand; een verschuifbare kraag houdt ze dicht. Het wegtrekken van de kraag (via een touw op afstand) ontgrendelt en lanceert.
- Pomp en manometer: een sta-fietspomp met manometer (of compressor) via een Schrader-autoventiel en een tuinslang, zodat we precies de gewenste druk kunnen instellen en aflezen.
- Basis: een stevige houten of PVC-voet, waterpas gesteld, met een instelbare hoek voor de lanceerhoek-proeven.

Veilig pompen op afstand betekent: pomp aansluiten, druk opbouwen tot de gewenste waarde op de manometer, daarna minimaal 5 m terug en lanceren via het touw.

## 8.2 Meten van de hoogte (apogeum)

De hoogte is onze belangrijkste meetwaarde. We gebruiken de trigonometrische methode als hoofdmethode, en houden een tweede methode achter de hand ter controle.

### Hoofdmethode – trigonometrie met hoekmeter

Een waarnemer staat op een bekende horizontale afstand L van het lanceerpunt en meet met een hoekmeter (of een telefoon-clinometer-app) de maximale kijkhoek θ op het moment van het apogeum. De hoogte volgt dan uit:

h = L · tan(θ) + h_oog

Met h_oog de ooghoogte van de waarnemer. Door twee waarnemers onder verschillende hoeken te plaatsen (bv. 90° uit elkaar) kunnen we de meting controleren en de zijwaartse afdrijving corrigeren.

### Controlemethode – tijd tot apogeum

Met een stopwatch meten we de tijd t_op tot het hoogste punt. In een eenvoudige (weerstandsloze) benadering geldt h ≈ ½ · g · t_op². Door luchtweerstand is dit een onderschatting, maar het is een goede, snelle controle naast de trigonometrische waarde. Optioneel kan een lichte altimeter in de neuskegel de hoogte direct loggen.

## 8.3 Meetprotocol en standaardisatie

1. Kies een open, vlak terrein, windstil weer (< ~2 Bft) en noteer datum, tijd, temperatuur en windrichting.
2. Stel de lanceerinstallatie waterpas en op de gewenste hoek; markeer een vaste waarnemerafstand L (bv. 20–30 m).
3. Voer de swing-test uit; lanceer alleen bij een stabiel resultaat.
4. Stel exact één variabele in (bv. vulfractie); houd alle andere instellingen identiek.
5. Lanceer minimaal 3–5 keer per instelling; noteer per vlucht de hoek/tijd en bijzonderheden (recht/tollen).
6. Bereken per instelling het gemiddelde en de spreiding (standaardafwijking) van de hoogte.
7. Verwerp duidelijke uitschieters (bv. mislukte afdichting) en noteer waarom.

Door deze opzet meten we het effect van één factor zuiver, met een eerlijke schatting van de meetonzekerheid.

## 8.4 Veiligheid (verplicht)

- Gebruik uitsluitend onbeschadigde PET-flessen die voor koolzuurhoudende drank zijn ontworpen; nooit melk-, sap- of gewone waterflessen, en nooit glas.
- Blijf binnen een veilig drukbereik. Begin laag (3–4 bar) en ga niet boven ~7 bar; bouw druk altijd geleidelijk op.
- Houd minimaal 5–10 m afstand en lanceer altijd via een touw op afstand. Sta nooit boven de raket gebogen tijdens het pompen.
- Draag een veiligheidsbril tijdens pompen en lanceren.
- Richt de raket nooit op mensen, dieren, gebouwen, wegen of (hoog)spanningslijnen; lanceer recht omhoog of licht van toeschouwers af.
- Test elk 3D-geprint drukvoerend onderdeel (nozzle, koppeling) eerst vol water achter een afscherming voordat je het met lucht en op hoogte gebruikt.
- Doe dit onder toezicht van een volwassene/begeleider en met toestemming voor de locatie.

# 9. Stappenplan en planning

Het onderzoek is opgedeeld in zeven fasen. De weken zijn indicatief en kunnen aan het eigen PWS-rooster worden aangepast.

Fase | Activiteit | Concrete stappen | Duur (indic.)
1 | Literatuur & ontwerp | Theorie verzamelen, onderzoeksvraag/hypothesen vastleggen, modellen en testopstelling ontwerpen | week 1–2
2 | Bouw & print | Lanceerinstallatie bouwen; model A en B vervaardigen; nozzle-/vin-/neuskegelreeksen 3D-printen en drukdelen testen; BOM inkopen | week 3–4
3 | Nulmeting & kalibratie | Meetmethode testen, afstand L ijken, swing-test, eerste proefvluchten met model A | week 5
4 | Hoofdmetingen | Per factor systematisch variëren (vulfractie, druk, nozzle, massa, vinnen, hoek), n ≥ 3–5 per instelling | week 6–8
5 | Modellen B/C | Geoptimaliseerd model en gekoppelde flessen meten en vergelijken | week 9
6 | Analyse | Grafieken (hoogte vs. factor), optimum bepalen, vergelijken met theorie, onzekerheid | week 10–11
7 | Verslag | Resultaten en conclusie uitschrijven, discussie en aanbevelingen, eindcontrole | week 12–13

# 10. Materiaallijst (BOM)

Onderstaande lijst dekt de lanceerinstallatie, de meetopstelling, de raketmodellen en de 3D-geprinte onderdelen. Prijzen zijn indicatieve Nederlandse richtprijzen (bouwmarkt / Action / bol.com); PET-flessen zijn in feite gratis en filament wordt per gebruikte hoeveelheid gerekend.

Onderdeel | Specificatie | Aantal | Prijs (€) | Bron
PVC-buis | ø ~22 mm, ca. 1 m (lanceerbuis) | 1 | 3 | Bouwmarkt
PVC-fittingen | T-stuk, eindkap, verloop | set | 6 | Bouwmarkt
Gardena-snelkoppeling | Slangstuk + kraanstuk (afdichting + release) | 1 | 8 | Tuincentrum
O-ringen | Assortiment + Viton 111 (nozzle-afdichting) | set | 6 | Bouwmarkt
Tuinslangringen | Rubber ring tussen nozzle en fles | set | 2 | Tuincentrum
Kabelbinders | Zwaar, 4,8 mm (ontgrendeling) | zak | 4 | Bouwmarkt
Fietspomp + manometer | Sta-pomp met drukmeter | 1 | 20 | Bol.com
Schrader-ventiel | Autoband-/fietsventiel | 1 | 3 | Bouwmarkt
Tuinslang | 2–3 m | 1 | 6 | Tuincentrum
PET-flessen | 1,0 / 1,5 / 2,0 L frisdrank | 6–8 | 0 | Statiegeld
3D-filament | PLA en/of PETG (drukdelen PETG) | 1 rol | 20 | Bol.com
Flexibel filament | Voor neuskegel (optioneel, veiliger) | klein | 10 | Bol.com
Plaatmateriaal vinnen | Reserve: PP-map / corflute / 3 mm PVC | 1 | 5 | Action
Boetseerklei | Ballast/neusgewicht | 1 | 3 | Action
Tape & lijm | Montagetape + PVC-lijm + 2K-lijm | set | 12 | Bouwmarkt
Hoekmeter / clinometer | Of gratis telefoon-app | 1 | 0–10 | Bol.com
Meetlint | 30–50 m | 1 | 10 | Bouwmarkt
Veiligheidsbril | 1 per persoon | 2 | 5 | Bouwmarkt
Optioneel: altimeter | Lichte hoogtelogger (bv. Jolly Logic) | 1 | 40–60 | Modelbouw

Indicatieve kerntotaal (zonder optionele altimeter): ongeveer €120–140. Met altimeter ongeveer €160–200. De 3D-geprinte onderdelen vervangen deels het losse plaatmateriaal en de speelgoed-neuskegels uit een traditionele bouw.

# 11. Meetonzekerheid en risico’s

- Hoekmeting: een fout van ±1° geeft bij 25 m al enkele tientallen centimeters hoogteafwijking; we meten daarom met twee waarnemers en herhalen.
- Wind: zijwind buigt de baan af en verstoort de aanname van een verticale vlucht; we lanceren alleen bij weinig wind en noteren afdrijving.
- Afdichting/druklek: lekt het O-ring-systeem, dan klopt de begindruk niet; zulke vluchten markeren we als ongeldig.
- Spreiding tussen vluchten: door n ≥ 3–5 herhalingen en het rapporteren van de standaardafwijking maken we de betrouwbaarheid zichtbaar.
- Aannames in de theorie (verwaarloosde luchtweerstand bij de tijdmethode, ideale uitstroom) bespreken we expliciet in de discussie van het eindverslag.

# 12. In-flight dataverzameling (ESP32) – optioneel

Een kleine microcontroller met sensoren in de neuskegel kan tijdens de vlucht zelf meten. Dit hoofdstuk is optioneel: het kernonderzoek (hoofdstukken 4–8) staat op zichzelf, maar een onboard meting versterkt de resultaten en is op vwo-niveau goed haalbaar. Er bestaat zelfs een vrijwel kant-en-klaar voorbeeld voor waterraketten (zie hoofdstuk 13).

## 12.1 Doel en meerwaarde

De grootste winst is dat we de tophoogte rechtstreeks aan boord meten met een barometrische druksensor, onafhankelijk van de trigonometrische meting vanaf de grond. Daarmee valideren we de hoofdmeetmethode en maken we de factorproeven (vulfractie, druk, nozzle) harder. Met een extra bewegingssensor meten we bovendien de versnelling tijdens de stuwfase.

## 12.2 Twee ambitieniveaus

Niveau 1 – barometrische hoogtelogger (de kern): één druksensor (BMP388; de firmware werkt ook met een BME680) meet de hoogte uit de luchtdruk en geeft direct het apogeum. De ESP32 logt naar zijn eigen geheugen en zet na de landing een wifi-accesspoint op, zodat je de meting op je telefoon downloadt – geen kwetsbaar SD-kaartje nodig.

Niveau 2 – met bewegingssensor: het gekozen Waveshare-bord heeft de 6-assige sensor (QMI8658, versneller + gyroscoop) al aan boord, zodat je het versnellings- en stuwprofiel meteen meelogt zonder extra hardware. Door te integreren krijg je ook een snelheidsschatting. Het interne flashgeheugen is ruim genoeg, dus een microSD-kaartje is niet nodig.

## 12.3 Welke data en koppeling aan de experimenten

- Apogeumhoogte (barometrisch) – valideert de trigonometrische methode; primaire uitkomst per instelling.
- Versnelling en piek-g (IMU) – maakt nozzlediameter- en drukproeven kwantitatief op de stuwfase zelf, niet alleen via de eindhoogte.
- Snelheid (door integratie) en temperatuur – extra context voor de discussie.

## 12.4 Beperkingen en afbakening

- g-bereik: een waterraket trekt kort tientallen g; de onboard QMI8658 (±16 g) klipt tijdens de stuwfase. De barometrische apogeummeting heeft daar geen last van. Een schoon stuw-g-profiel vraagt een high-g-versneller (bv. ADXL375 ±200 g) – dat houden we als stretch buiten scope.
- Druksensorruis (≈ ±1 m) en luchtstroming langs een open poortje verstoren de meting bij hoge snelheid; het apogeum (snelheid ≈ 0) blijft betrouwbaar. Gebruik een klein statisch ventilatiegaatje in de neuskegel.
- Waterdichtheid: de elektronica zit droog en afgesloten in de neuskegel (boven het luchtkussen), nooit in de watersectie.
- Gewicht: de payload (~30–60 g) verandert de prestatie; behandel ‘met payload’ als aparte configuratie en meng het niet met no-payload-vluchten in één factorreeks. Controleer na het inbouwen opnieuw de swing-test, want de payload verschuift het zwaartepunt naar voren.
- Recovery: je moet de raket én de data heel terugkrijgen – land op gras of gebruik een recovery-systeem.

## 12.5 Payload-neuskegel en fleskeuze

De elektronica bepaalt mede de keuze van fles en neuskegel. De fles vliegt halsnaar-beneden, dus de gesloten flesbodem wijst omhoog en is in de vlucht de neus. De payload-neuskegel is daarom een holle kap die over de flesbodem schuift – niet een neuskegel die op de schroefdraad past, want die zit onderaan bij de nozzle.

Beste combinatie voor de Nederlandse situatie: een standaard 1,5 L koolzuurhoudende frisdrank-PET-fles (bijvoorbeeld Coca-Cola, Fanta of een supermarkt-huismerk cola) met de gangbare lichte PCO1881-hals van 29 mm. Deze flessen zijn drukbestendig (gemaakt voor koolzuur), overal te krijgen (statiegeld €0,25), hebben met Ø ~90 mm genoeg ruimte voor de payload, en hun standaardhals zorgt dat geprinte nozzles en koppelingen passen. Houd één merk en vorm consequent aan voor reproduceerbaarheid.

De bijbehorende neuskegel is een 3D-geprinte holle ogief, afgestemd op Ø ~90 mm, die over de flesbodem schuift en intern een schuimcradle voor de print bevat. Voorzie hem van een klein statisch ventilatiegaatje voor de druksensor en een flexibele (TPU) tip voor een veilige landing. Een afneembaar of friction-fit deksel maakt de elektronica bereikbaar.

## 12.6 Elektronica-BOM (bestellijst)

Voor de gekozen opzet gebruiken we het Waveshare ESP32-S3-Touch-LCD-1.69-bord. Dat scheelt onderdelen: de 6-assige IMU (QMI8658), het touchscherm en het lithium-laadcircuit zitten al op het bord. We prikken er alleen een losse barometer (BMP388) bij voor de hoogtemeting, en een LiPo met de juiste stekker. Prijzen zijn indicatieve Nederlandse richtprijzen (Amazon.nl; AliExpress is goedkoper met langere levertijd).

Onderdeel | Specificatie / opmerking | Prijs (€)
Bord | Waveshare ESP32-S3-Touch-LCD-1.69 (ESP32-S3, 240×280 LCD + touch, onboard QMI8658 IMU, MX1.25 accu-lader) | 33
Druksensor | BMP388 module (CJMCU-388), I2C – de hoogtemeting | 11
LiPo-accu | 3,7 V, 300–500 mAh, met MX1.25 (1,25 mm) stekker – polariteit controleren! | 10
Proto/bedrading | Dunne (soldeer)draad/Dupont om de BMP388 op de I2C-pinnen te hangen | 4
Diversen | Schuim, krimpkous, dubbelzijdig tape, schroefjes | 5

Indicatief totaal: ongeveer €60–65. Niet nodig: een losse IMU (zit op het bord), een aan/uit-schakelaar (het bord heeft een aan/uit-knop) en een microSD (intern flash volstaat). Laden gaat via USB-C.

## 12.7 Bedrading (I2C)

De BMP388 gaat op dezelfde I2C-bus als de onboard QMI8658 en het touchscherm. De adressen verschillen (BMP388 0x76/0x77, QMI8658 0x6B, touch 0x15), dus ze kunnen samen op één bus. De accu gaat op de MX1.25-connector van het bord; controleer de polariteit vóór het insteken.

BMP388-pin | Bord-pin | Opmerking
VCC | 3V3 | voeding
GND | GND | massa
SDA | GPIO11 (SDA) | I2C-datalijn
SCL | GPIO10 (SCL) | I2C-kloklijn
– | MX1.25-connector | LiPo; polariteit controleren!

## 12.8 Software (toestandsmachine met touch-UI)

De sketch (Arduino IDE; libraries Arduino_GFX, SensorLib en Adafruit BMP3XX) gebruikt het touchscherm als bediening. Het verloop: een HOME-scherm toont de stats van de laatste vlucht met een START-knop; na START kalibreert het bord en wacht het op de lancering; tijdens de vlucht logt het op 50 Hz naar het interne flash (hoogte uit de BMP388, versnelling uit de QMI8658) en toont het live de hoogte; na de landing verschijnt een RESULTAAT-scherm met apogeum, maximale versnelling en vluchttijd, plus een VERZEND-knop die een wifi-accesspoint opent zodat je de data als CSV downloadt. De fysieke BOOT-knop werkt als START-fallback als de touch nog afgesteld moet worden.

# 13. Bronnen

Hieronder staan alle geraadpleegde bronnen met volledige URL, geordend per onderwerp. Alle webpagina’s zijn geraadpleegd in juni 2026. In het eindverslag worden ze volgens de schoolafspraken (bv. APA) definitief opgemaakt.

## 13.1 Natuurkunde, aandrijving en vluchtmodel

- Real World Physics Problems – Water Rocket Physics (stuwkracht, optimale druk) — https://www.real-world-physics-problems.com/water-rocket-physics.html
- NASA – Optimize a Water Rocket Engine (SLS educator activity; optimale water-luchtverhouding) — https://www.nasa.gov/wp-content/uploads/2021/11/sls-activity-four-optimize-a-water-rocket.pdf
- Dean’s Benchtop (BYU) – Water-rocket flight equations (tijd-tot-apogeum methode) — https://www.et.byu.edu/~wheeler/benchtop/flight.php
- Engineer Fix – Safe and Effective Water Rocket Launcher (optimale ⅓-vulverhouding, launcher) — https://engineerfix.com/how-to-build-a-safe-and-effective-water-rocket-launcher/

## 13.2 Aerodynamica en stabiliteit (zwaartepunt/drukpunt)

- Science Learning Hub – Rocket aerodynamics (neuskegel, vinnen, CM/CP) — https://www.sciencelearn.org.nz/resources/392-rocket-aerodynamics
- NASA Glenn Research Center – Model Rocket Stability (swing-test, restoring force) — https://www.grc.nasa.gov/www/k-12/VirtualAero/BottleRocket/airplane/rktstab.html
- Science Buddies – Model Rocket Aerodynamics: Stability — https://www.sciencebuddies.org/science-fair-projects/project-ideas/Aero_p002/aerodynamics-hydrodynamics/model-rocket-stability
- Whitebox Learning – Rocket Stability (statische marge / kaliber-vuistregel) — https://www.whiteboxlearning.com/c/application/water-rocket/r1l0305.html
- Nakka Rocketry – Introduction to Rocket Design: Fins (drukpunt, normaalkracht) — https://www.nakka-rocketry.net/RD_fin.htm

## 13.3 Lanceerinstallatie

- US Water Rockets – Gardena Launcher tutorial — http://www.uswaterrockets.com/construction_&_tutorials/Gardena_Launcher/tutorial.htm
- US Water Rockets – Cable Tie Launcher tutorial — http://www.uswaterrockets.com/construction_&_tutorials/cable_tie_launcher/tutorial.htm
- US Water Rockets – Clark Cable Tie Release Mechanism — http://www.uswaterrockets.com/construction_&_tutorials/cable_tie_release_mechanism/tutorial.htm

## 13.4 Hoogtemeting en altimeters

- Estes Rockets – Altitude Trackers (Altitrak, trigonometrie) — https://estesrockets.com/collections/altitude-trackers
- Apogee Components – Jolly Logic AltimeterThree (loggende altimeter, gewicht) — https://www.apogeerockets.com/Electronics-Payloads/Altimeters/Jolly-Logic-AltimeterThree

## 13.5 3D-printen: systemen, onderdelen en modelbestanden

- Raketfued – 3D-print waterraketonderdelen (nozzles 4–10 mm, neuskegels, recovery; pressure-test advies) — https://www.raketfuedrockets.com/en/3dprinting.htm
- US Water Rockets – 3D Printed Gardena Nozzle tutorial — http://www.uswaterrockets.com/3D_Printing/3D_Gardena_Nozzle/tutorial.htm
- US Water Rockets – 3D Printed Self Aligning Fin Brackets — http://www.uswaterrockets.com/3D_Printing/3D_Self_Aligning_Fin_Bracket/tutorial.htm
- Thingiverse (USWaterRockets) – Water Rocket Gardena Quick Release Nozzle (thing:781367) — https://www.thingiverse.com/thing:781367
- Thingiverse (Kendalf) – Soda Bottle Water Rocket Nozzle, easy print (thing:7174682) — https://www.thingiverse.com/thing:7174682
- Printables (sage) – Gardena pop bottle water rocket: neuskegel + nozzle + vinnen (model 976435) — https://www.printables.com/model/976435-gardena-pop-bottle-water-rocket
- Printables (HAL_9000) – 2L Water Rocket kit: vinnen + losvallende neuskegel (model 208609) — https://www.printables.com/model/208609-2l-water-rocket-kit
- Printables (fl_mike) – Rocket Fin Alignment Jig, 3- en 4-vin (model 214186) — https://www.printables.com/model/214186-rocket-fin-alignment-jig
- Printables (Steamboat Ed) – Rocket Fin Alignment Jig (model 194071) — https://www.printables.com/model/194071-rocket-fin-alignment-jig
- Estes Rockets – Scorpio 3D Pro Series II (twist-lock fin can, uitwisselbare vinvormen) — https://estesrockets.com/products/scorpio-3d
- Thingiverse (mockfrog) – Gardena water rocket launcher + nozzle (thing:3127479) — https://www.thingiverse.com/thing:3127479
- Streamhead – 3D Printed Water Rocketry (praktijkervaring nozzle printen vs. kopen) — https://www.streamhead.com/3d%20printing/2019/10/11/3d-printed-water-rocketry.html

## 13.6 In-flight dataverzameling (ESP32 / Arduino)

- Electromaker – Triton Water Rocket Flight Computer (Xiao ESP32-S3, BMP280 + MPU6050, 50 Hz, parachute) — https://www.electromaker.io/project/view/water-rocket-flight-computer
- Random Nerd Tutorials – Altimeter Datalogger: ESP32 met BMP388 (wifi-accesspoint, logging) — https://randomnerdtutorials.com/altimeter-datalogger-esp32-bmp388/
- bdureau – RocketFlightLogger / AltiMulti (ESP32- en Arduino-vluchtlogger, open source) — https://github.com/bdureau/RocketFlightLogger
- Rocketry Forum – Arduino-based flight computers (Nano + BMP280 + MPU6050 @ 50 Hz) — https://www.rocketryforum.com/threads/lets-see-your-arduino-based-flight-computers.181423/
- Waveshare Wiki – ESP32-S3-Touch-LCD-1.69 (pinout, QMI8658, CST816, TFT_eSPI/LVGL) — https://www.waveshare.com/wiki/ESP32-S3-Touch-LCD-1.69
- moononournation – Arduino_GFX (LCD-library voor ST7789, gebruikt voor het scherm) — https://github.com/moononournation/Arduino_GFX
- lewisxhe – SensorLib (QMI8658 IMU en CST816 touch in één library) — https://github.com/lewisxhe/SensorLib

# Bijlage A – Bedrading en montage van de vluchtcomputer

Deze bijlage hoort bij hoofdstuk 12. Bij het Waveshare ESP32-S3-Touch-LCD-1.69-bord prik je alleen de BMP388-barometer bij; de QMI8658-IMU, het touchscherm en het accu-laadcircuit zitten al op het bord. De BMP388 gaat op dezelfde I2C-bus (SDA en SCL) plus voeding (3V3 en GND). Omdat de I2C-adressen verschillen (BMP388 0x76/0x77, QMI8658 0x6B, touch 0x15), werken ze samen op één bus.

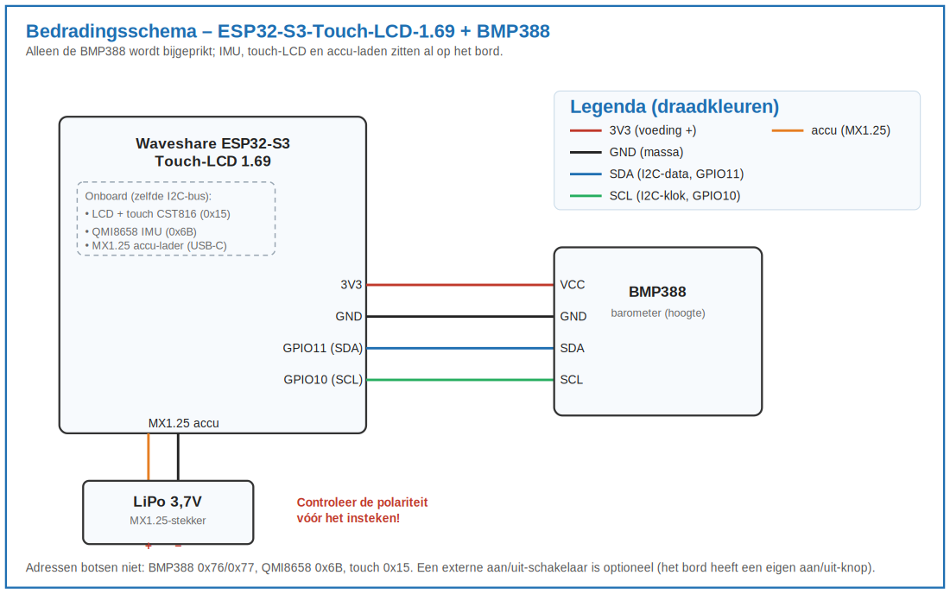
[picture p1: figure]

Figuur A.1 – Bedradingsschema: ESP32-S3-Touch-LCD-1.69 met losse BMP388 (I2C).

## Montagestappen

1. Soldeer op de BMP388 de meegeleverde pinheaders, of soldeer de draden rechtstreeks.
2. Verbind VCC van de BMP388 met 3V3 van het bord, en GND met GND.
3. Verbind SDA van de BMP388 met GPIO11 (SDA) en SCL met GPIO10 (SCL) – dezelfde I2C-bus als de onboard IMU en touch.
4. Sluit de LiPo aan op de MX1.25-connector van het bord. Controleer eerst de polariteit tegen de markering op het bord; klopt die niet, wissel dan de crimpcontacten in de connector om.
5. Controleer alle verbindingen op kortsluiting; isoleer blanke soldeerpunten met krimpkous of een beetje lijm.
6. Zet de elektronica met schuim klemvast in de holle neuskegel (de droge sectie boven het luchtkussen). Maak één klein statisch ventilatiegaatje voor de druksensor.
7. Laad de LiPo via de USB-C van het bord; een aparte lader is niet nodig.

Veiligheid: laad LiPo-accu’s alleen onder toezicht, gebruik geen beschadigde accu’s, en houd de elektronica volledig droog en gescheiden van de watersectie.

# Bijlage B – Arduino-sketch (firmware)

Deze sketch hoort bij hoofdstuk 12 en is geschreven voor het Waveshare ESP32-S3-Touch-LCD-1.69-bord in de Arduino IDE. Hij gebruikt het touchscherm als bediening: een START-knop start de meting, daarna detecteert hij de lancering, logt op 50 Hz naar het interne flashgeheugen (hoogte uit de BMP388, versnelling uit de onboard QMI8658), bepaalt het apogeum en toont na de landing de stats; een VERZEND-knop opent een wifi-accesspoint waarmee je de data als CSV downloadt.

## Installatie en gebruik

1. Installeer in de Arduino IDE de ESP32-board-package (Boards Manager: “esp32” van Espressif) en kies het board “ESP32S3 Dev Module” (PSRAM: OPI PSRAM; USB CDC On Boot: Enabled).
2. Installeer via Bibliotheken beheren: “GFX Library for Arduino” (Arduino_GFX), “SensorLib”, en “Adafruit BMP3XX Library” (met “Adafruit Unified Sensor” en “Adafruit BusIO”).
3. Controleer bovenin de sketch de LCD- en I2C-pinnen tegen de Waveshare-wiki van jouw bord-revisie, en upload via USB-C.
4. In het veld: tik op het scherm op START (of gebruik de fysieke BOOT-knop). Het bord kalibreert en wacht op de lancering.
5. Plaats de raket en lanceer; tijdens de vlucht toont het scherm live de hoogte en versnelling terwijl er gelogd wordt.
6. Na de landing verschijnt het RESULTAAT-scherm (apogeum, max versnelling, vluchttijd). Tik op VERZEND om het wifi-netwerk “Waterraket” te openen.
7. Verbind je telefoon met dat netwerk (wachtwoord raket1234), open het getoonde IP-adres in de browser en download flight.csv.
8. Open het CSV-bestand in de logsheets/Excel en zet de hoogte tegen de tijd uit; de piek is het apogeum.
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

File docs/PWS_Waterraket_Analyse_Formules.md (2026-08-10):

# Formules en aannames van de vluchtanalyse

Bijlage bij het profielwerkstuk. Beschrijft precies hoe `webapp/index.html` uit
de meetreeks van de vluchtcomputer de getallen berekent die in het verslag
komen. Elke formule hieronder staat ook in de applicatie zelf, achter het
vraagteken bij de betreffende grootheid.

De applicatie draait volledig in de browser. Er is geen server, geen bouwstap
en geen internetverbinding nodig: open `webapp/index.html` en laad de
CSV-bestanden in.

---

## 1. Het meetbestand

De vluchtcomputer schrijft per vlucht een bestand van deze vorm:

```
# vlucht 4, gestart 2026-08-09 14:07
t_ms,hoogte_m,druk_hPa,temp_C,ax_g,ay_g,az_g
0,0.12,1013.40,21.3,0.02,-0.01,1.00
20,0.31,1013.38,21.3,0.05,0.02,1.02
```

| Kolom | Betekenis |
|---|---|
| `t_ms` | tijd in ms vanaf de lanceerdetectie |
| `hoogte_m` | barometrische hoogte boven het lanceerpunt |
| `druk_hPa` | absolute luchtdruk |
| `temp_C` | temperatuur |
| `ax_g, ay_g, az_g` | specifieke kracht per as, in eenheden g, bereik 16 g |

Twee eigenschappen van de firmware zijn belangrijk bij het lezen van de
uitkomsten:

1. De kopregel wordt met `println` geschreven en eindigt op CRLF, de meetregels
   met `printf` en eindigen op LF. Het bestand heeft dus gemengde regeleindes.
   De parser gaat om met CRLF, LF en losse CR.
2. Het log begint pas als de barometer meer dan `LAUNCH_RISE_M` = 3,0 m
   aanwijst. Bij een echte vlucht ontbreekt dus zowel het begin van de stuwfase
   als de rustige periode voor de lancering. De applicatie meldt dat en schakelt
   over op een andere ruisschatting (zie hoofdstuk 4).

De versnellingsmeter meet de **specifieke kracht**, niet de versnelling van de
raket. In rust leest hij 1 g, in vrije val 0 g. Dat is de meest gemaakte
denkfout bij het aflezen van zo'n grafiek.

---

## 2. Filtering

De hoogtereeks wordt gefilterd met een **Savitzky-Golay filter**. In een venster
van `w` monsters (standaard 21, dat is 0,42 s bij 50 Hz) wordt met kleinste
kwadraten een polynoom van graad `d` (standaard 2) gepast, en de gefilterde
waarde is die polynoom in het midden van het venster:

```
h_f(i) = som_j c_j h(i + j),   j = -(w-1)/2 .. +(w-1)/2
```

met `c` de rij van de pseudo-inverse `(X^T X)^-1 X^T` die bij het middelpunt
hoort. Aan de randen wordt de polynoom van het eerste of laatste volledige
venster op de werkelijke positie geevalueerd, zodat de reeks even lang blijft.

Waarom dit filter en niet een voortschrijdend gemiddelde: rond het apogeum is de
baan parabolisch, en een polynoom van graad 2 volgt een parabool exact. Een
voortschrijdend gemiddelde zou de top afvlakken en het apogeum systematisch te
laag maken.

Ontbrekende metingen worden **niet** ingevuld. Zit er een NaN in de invoer, dan
blijft die op die plek staan en breekt de lijn in de grafiek af.

---

## 3. De grootheden

| Grootheid | Formule |
|---|---|
| Apogeum | `h = a0 + a1 (t - t0) + a2 (t - t0)^2`, top: `H = a0 - a1^2 / (4 a2)` |
| Tijd tot apogeum | `t_top = t0 - a1 / (2 a2)` |
| Snelheid | `v(i) = (h_f(i+m) - h_f(i-m)) / (t(i+m) - t(i-m))` |
| Maximale snelheid | `v_max = max v(i)` |
| Versnelling | `abs(a) = sqrt(ax^2 + ay^2 + az^2)` |
| Maximale versnelling | `a_max = max abs(a)`, in m/s2 maal 9,80665 |
| Stuwtijd | `t_stuw = t_eind - t_begin`, de eerste aaneengesloten periode met `abs(a) > drempel` |
| Vluchttijd | `t_vlucht = t_laatste - t_eerste` met `h_f > drempel` |
| Daalsnelheid | helling `b` van `h = a + b t` over het laatste deel van de daling |

### 3.1 Apogeum

Het hoogste punt van het gefilterde signaal wijst de top aan. Rond dat punt
wordt over `± 0,40 s` (instelbaar) een parabool gepast door de **ongefilterde**
metingen, met gewone kleinste kwadraten. De top van die parabool is het
apogeum.

Twee redenen om de fit op de ruwe metingen te doen en niet op de gefilterde:

* De kleinste-kwadratentheorie geeft dan meteen de standaardfout van de
  tophoogte, want de meetfouten zijn dan nog ongecorreleerd.
* Vlak bij het apogeum is de snelheid nul, dus ook de luchtweerstand. De baan is
  daar zuiver parabolisch en een parabool over 0,8 s past bijna perfect.

De top ligt tussen twee metingen in; met de fit is hij nauwkeuriger dan het
hoogste meetpunt zelf.

### 3.2 Snelheid

De snelheid is het gecentreerde verschil van de gefilterde hoogte, met halve
stap `m` (standaard 1). Belangrijke kanttekening: een breed filtervenster maakt
de **snelheidspiek** lager dan hij werkelijk was, want die piek duurt maar kort.
Het apogeum heeft daar nauwelijks last van, de maximale snelheid wel. Op de
schone testvlucht kost het standaardvenster van 21 monsters ongeveer 0,2 m/s op
een piek van 25 m/s. Wie de piek scherper wil, kan het venster in de interface
verkleinen; het apogeum verandert daar nauwelijks van.

### 3.3 Stuwtijd

De eerste aaneengesloten periode waarin `abs(a)` boven de drempel (standaard
3 g) blijft. Begin en eind worden lineair geinterpoleerd tussen de twee metingen
rond de drempelpassage, zodat de uitkomst niet aan het meetraster van 20 ms
vastzit. Een latere piek, bijvoorbeeld de klap bij de landing, telt niet mee.
Valt de grootste versnelling van het hele log na het apogeum, dan meldt de
applicatie dat expliciet.

### 3.4 Aftopping bij 16 g

De QMI8658 staat in de firmware op een bereik van 16 g. Metingen die die grens
raken zijn afgetopt: de werkelijke versnelling was hoger. De applicatie telt hoe
vaak dat gebeurt, tekent de grens als lijn in de grafiek en waarschuwt erbij.

---

## 4. Meetonzekerheid

### 4.1 De ruis op de hoogtemeting

Eerste keus is de **rustige periode voor de lancering**: de metingen tot het
moment dat de versnelling de stuwdrempel passeert. Daarvan wordt de
standaardafwijking genomen:

```
sigma_h = sqrt( som (h_i - h_gem)^2 / (n - 1) )
```

Staan er minder dan 10 metingen voor de lancering in het log, wat bij de huidige
firmware het geval is (zie hoofdstuk 1), dan valt de applicatie **zichtbaar**
terug op de spreiding van de metingen rond het gefilterde signaal:

```
sigma_h = sd(h - h_f) / sqrt(1 - c0)
```

met `c0` het centrale gewicht van het filter. Die correctie is nodig omdat het
filter zichzelf mee-past aan het meetpunt, waardoor de rest te klein uitvalt.
In de interface staat per vlucht welke van de twee methoden is gebruikt.

### 4.2 De onzekerheid op het apogeum

Twee bijdragen, kwadratisch opgeteld en vermenigvuldigd met de dekkingsfactor
`k` (standaard 2, ongeveer 95 procent):

```
u(H) = k * sqrt( (sigma_h * L)^2 + (H_parabool - H_filter)^2 )
```

* `sigma_h * L` is de meetruis, doorgerekend naar de top van de fit. De
  hefboomfactor komt uit de kleinste-kwadratentheorie:
  `L = sqrt( x_top^T (X^T X)^-1 x_top )` met `x_top = [1, dt_top, dt_top^2]`.
  Omdat de fit over ongeveer 41 metingen middelt, is `L` ongeveer 0,23: de
  onzekerheid van de top is dus veel kleiner dan de ruis op een losse meting.
* `H_parabool - H_filter` is het verschil tussen de twee methoden voor de
  tophoogte. Die term groeit vanzelf zodra de twee methoden uit elkaar lopen,
  bijvoorbeeld bij veel ruis of bij een afgebroken log.

Hoe goed deze band klopt is nagerekend met 200 gesimuleerde ruisige vluchten
(ruis 0,40 m, bekend apogeum 30,00 m):

| maat | uitkomst |
|---|---|
| aandeel vluchten waarbij de band de werkelijke waarde bevat | 97,0 % |
| systematische fout van de schatter | +0,016 m |
| gemiddelde absolute afwijking | 0,067 m |

Bij `k = 2` hoort ongeveer 95 procent, dus de band is eerder iets ruim dan te
krap. Herhalen met `node test/gauntlet.js --breed`.

---

## 5. Vergelijken en verbanden

Per groep (alle vluchten met dezelfde waarde van de gekozen instelvariabele):

```
gemiddelde  x_gem = (1/n) som x_i
spreiding   s     = sqrt( som (x_i - x_gem)^2 / (n - 1) )
standaardfout      s / sqrt(n)
```

Een spreiding heeft minstens twee herhalingen nodig. Bij een groep met een
enkele vlucht staat een streepje, geen nul.

De trendlijn is een kleinste-kwadratenfit door **alle losse vluchten**, niet
door de groepsgemiddelden, zodat een instelling met meer herhalingen ook
zwaarder meetelt. Kwaliteit van de fit:

```
R2   = 1 - SSR / SST        deel van de spreiding dat de lijn verklaart
RMSE = sqrt( SSR / n )      in meters, dus direct te vergelijken met u(H)
```

---

## 6. Het theoretische model

Twee fasen. Alle symbolen staan in de tabel in hoofdstuk 7.

### 6.1 Stuwfase

De samengeperste lucht in de fles zet uit en drukt het water door de nozzle naar
buiten. De uitzetting is adiabatisch:

```
p(V) = p0 * (V0 / V)^gamma
```

met `p0` de absolute begindruk (`manometerdruk + p_atm`) en `V0` het beginvolume
lucht, `V0 = (1 - f) * V_fles`.

De uitstroomsnelheid van het water volgt uit Bernoulli:

```
v_e = sqrt( 2 (p - p_atm) / rho_water )
```

Daaruit de volumestroom en de stuwkracht:

```
dV/dt = Cd * A_n * v_e
m_punt = rho_water * Cd * A_n * v_e
F      = m_punt * v_e = 2 * Cd * A_n * (p - p_atm)
```

De massa van de raket neemt af doordat het water eruit gaat:

```
m(t) = m_leeg + rho_water * (V_fles - V)
```

En de bewegingsvergelijking, met luchtweerstand:

```
m dv/dt = F - m g - 0,5 * rho_lucht * Cw * A * v * abs(v)
```

Zolang de raket nog op de installatie staat en de stuwkracht het gewicht niet
overwint, draagt de installatie de raket en is de versnelling nul.

De stuwfase eindigt als het water op is (`V = V_fles`) of als de druk in de fles
tot de buitenluchtdruk is gezakt. In dat tweede geval blijft er water in de
fles; dat gaat als dode massa mee omhoog en de applicatie meldt het.

### 6.2 Ballistische fase

```
m_leeg dv/dt = - m_leeg g - 0,5 * rho_lucht * Cw * A * v * abs(v)
```

tot `v = 0`. Die hoogte is het theoretische apogeum.
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

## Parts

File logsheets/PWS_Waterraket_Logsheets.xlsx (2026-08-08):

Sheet: Instructies
Waterraket PWS – Meet- en logsheets
Vul per lancering één regel in op het tabblad 'Vluchtlog'. Blauwe kolommen typ je zelf; de hoogte wordt automatisch berekend.
Werkwijze
1. | Varieer steeds één factor; houd de rest gelijk. Geef elke meetreeks een korte 'Serie-tag' (bv. nozzle-6mm).
2. | Lanceer minimaal 3–5 keer per instelling en log elke vlucht apart.
3. | Noteer hoek θ (op het hoogste punt), afstand L en ooghoogte; de kolom 'Hoogte (trig)' rekent het uit.
4. | Meet ter controle ook de tijd tot het hoogste punt (t_op); de kolom 'Hoogte (tijd)' geeft een tweede schatting.
5. | Markeer of de vlucht stabiel was en of hij geldig is (geen lek/misser).
6. | Op tabblad 'Samenvatting' typ je je serie-tags; gemiddelde, spreiding en aantal verschijnen automatisch.
Gebruikte formules
Hoogte (trig) | h = L · tan(θ) + ooghoogte
Hoogte (tijd) | h ≈ ½ · g · t_op² (g = 9,81 m/s²; onderschat door luchtweerstand)
Spreiding | Standaardafwijking over de geldige vluchten van een serie.
Veiligheid (kort)
• | Alleen frisdrank-PET-flessen; begin laag (3–4 bar), niet boven ~7 bar.
• | Minimaal 5–10 m afstand, lanceren via touw, veiligheidsbril, nooit op mensen richten.
• | 3D-geprinte drukdelen eerst vol water achter een afscherming testen.

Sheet: Vluchtlog
Vluchtlog
Blauw = zelf invullen · Zwart = automatisch berekend
Vlucht # | Datum | Model | Factor onderzocht | Serie-tag | Vulfractie (%) | Begindruk (bar) | Nozzle Ø (mm) | Extra massa (g) | Vinnen (aantal/maat) | Lanceerhoek (°) | Afstand L (m) | Hoek θ (°) | Ooghoogte (m) | Hoogte trig (m) | Tijd t_op (s) | Hoogte tijd (m) | Stabiel? | Geldig? | Opmerkingen | h² (hulp)

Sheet: Samenvatting
Samenvatting per meetreeks
Typ links de serie-tags die je in de Vluchtlog hebt gebruikt; de rest rekent automatisch (alleen geldige vluchten meetellen kun je doen door foute regels leeg te laten).
Serie-tag | Gemiddelde hoogte (m) | Spreiding SD (m) | Aantal n | Min (m) | Max (m)

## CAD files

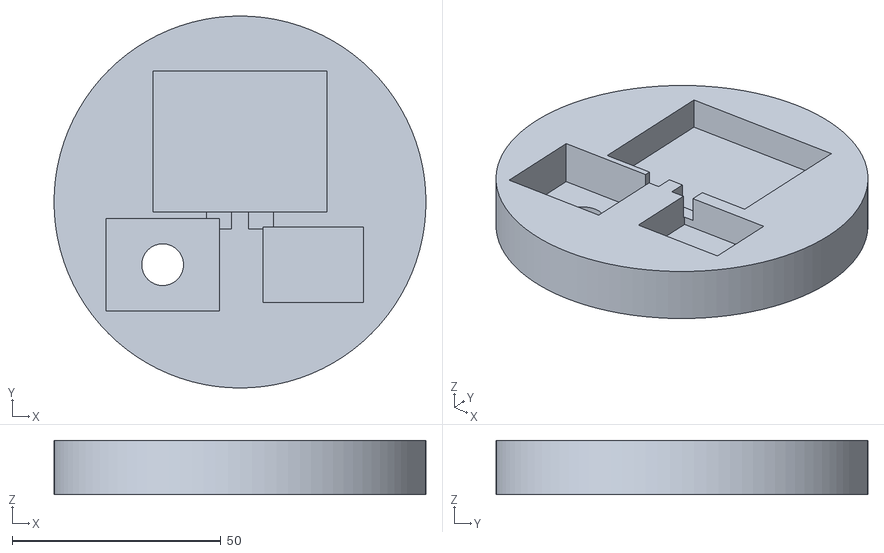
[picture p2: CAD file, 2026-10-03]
hardware/archief/PWS_Waterraket_Tray_rond.stl
89.0 x 89.0 x 13.0

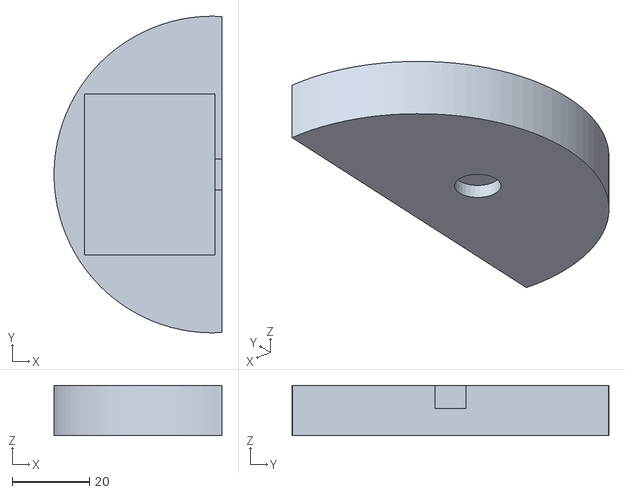
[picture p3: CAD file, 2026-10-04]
hardware/PWS_Waterraket_Tray_A.stl
43.5 x 82.0 x 13.0

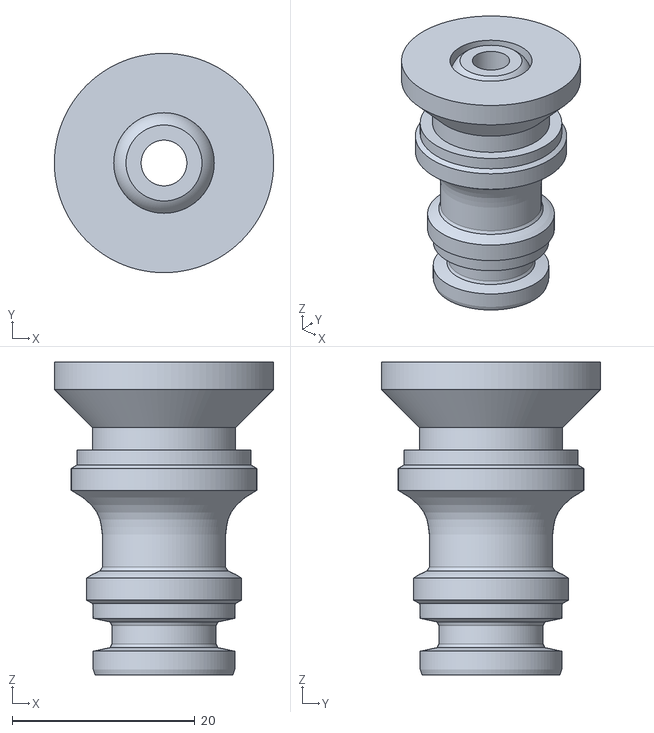
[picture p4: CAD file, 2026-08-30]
hardware/archief/PWS_Waterraket_NozzleGardenaDop_05mm.stl
24.0 x 24.0 x 34.2

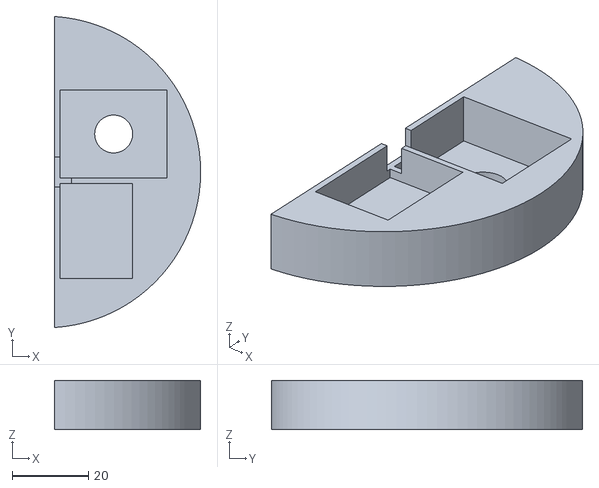
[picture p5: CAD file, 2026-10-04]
hardware/PWS_Waterraket_Tray_B.stl
38.5 x 81.8 x 13.0

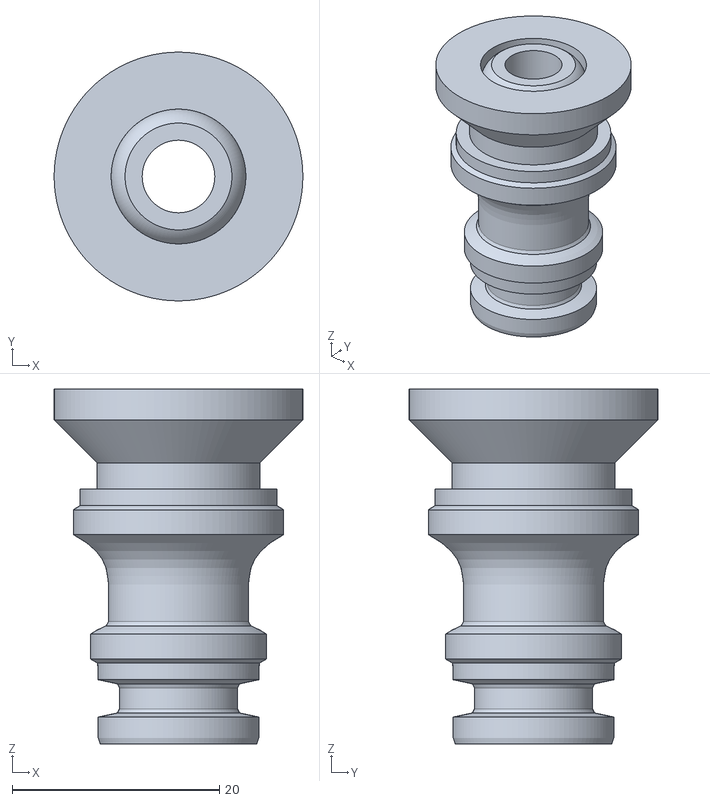
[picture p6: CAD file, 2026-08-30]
hardware/archief/PWS_Waterraket_NozzleGardenaDop_07mm.stl
24.0 x 24.0 x 34.2

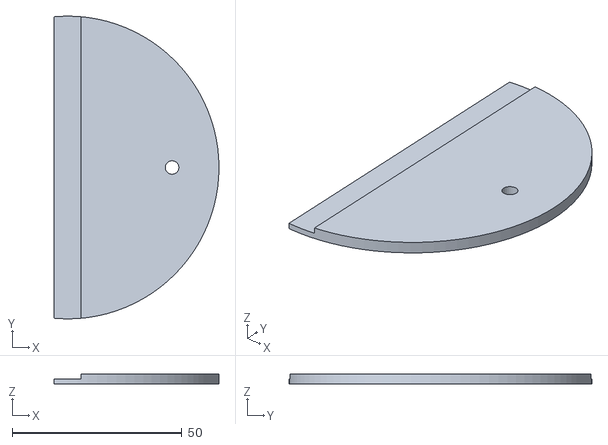
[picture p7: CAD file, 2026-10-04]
hardware/PWS_Waterraket_Recovery_Schot_B.stl
48.5 x 89.1 x 3.00

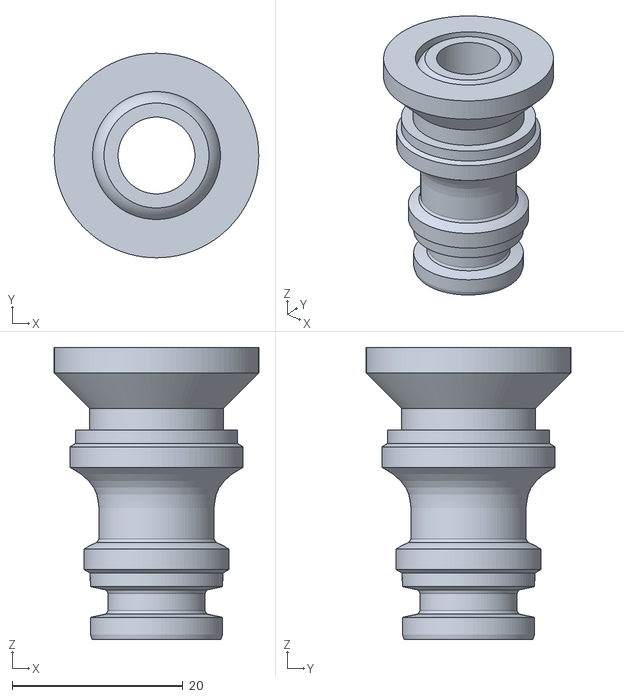
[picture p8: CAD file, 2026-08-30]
hardware/archief/PWS_Waterraket_NozzleGardenaDop_09mm.stl
24.0 x 24.0 x 34.2

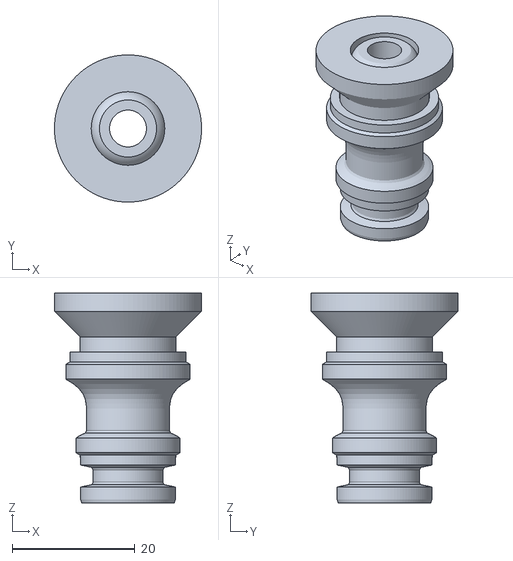
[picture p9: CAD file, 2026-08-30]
hardware/archief/PWS_Waterraket_NozzleGardenaDop_06mm.stl
24.0 x 24.0 x 34.2

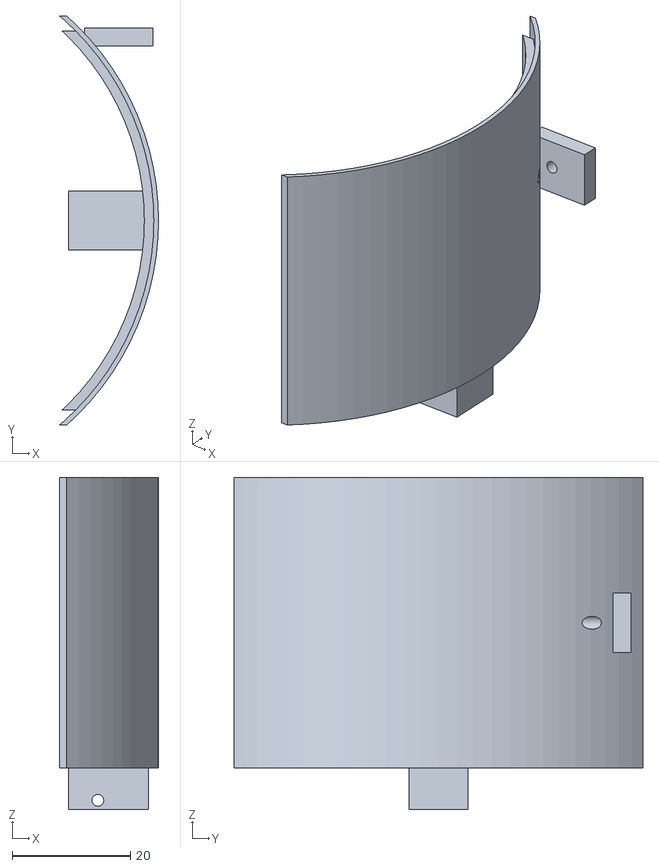
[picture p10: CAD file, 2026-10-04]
hardware/PWS_Waterraket_Recovery_Deur.stl
16.7 x 69.1 x 56.1

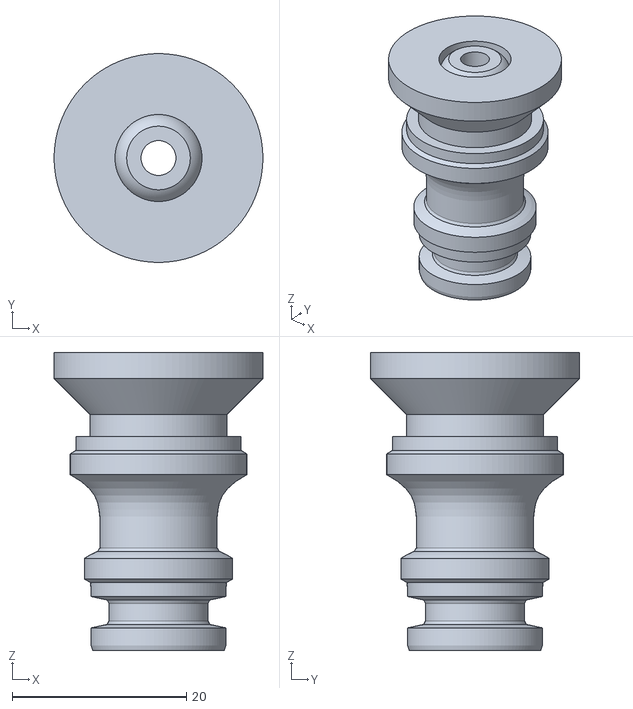
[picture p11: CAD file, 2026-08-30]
hardware/archief/PWS_Waterraket_NozzleGardenaDop_04mm.stl
24.0 x 24.0 x 34.2

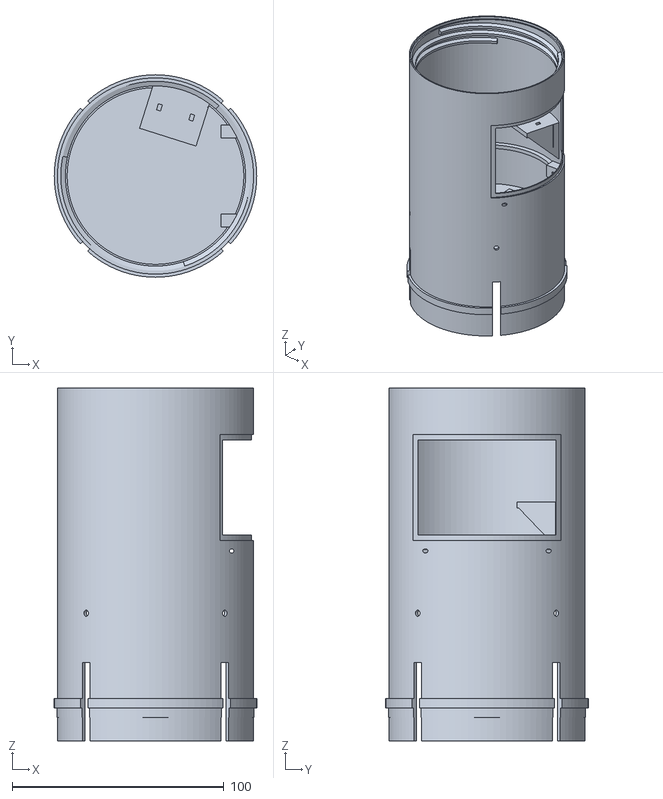
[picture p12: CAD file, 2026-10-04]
hardware/PWS_Waterraket_Recovery_Romp.stl
95.7 x 95.7 x 166.8

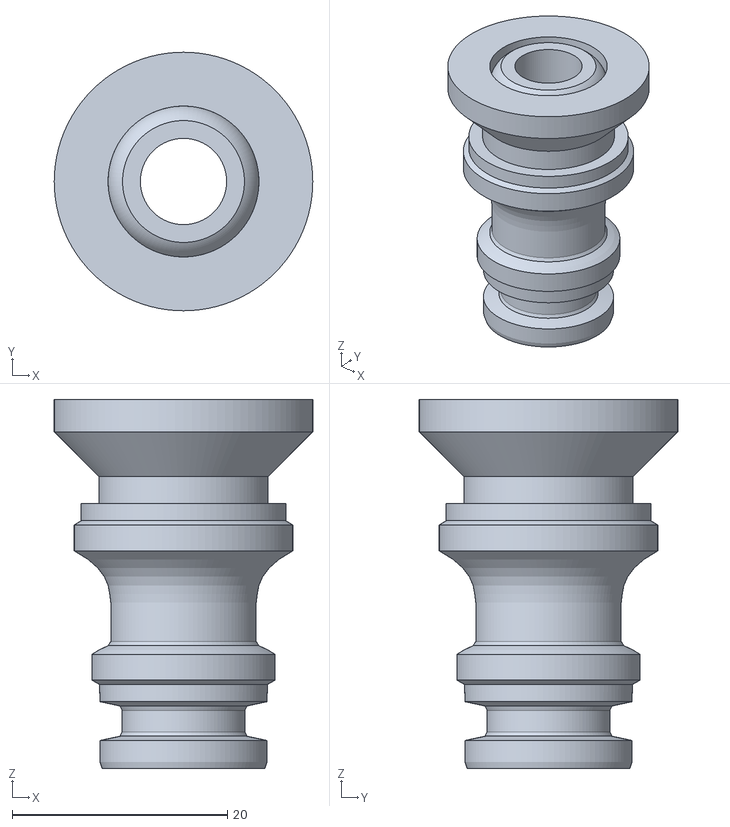
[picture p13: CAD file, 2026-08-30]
hardware/archief/PWS_Waterraket_NozzleGardenaDop_08mm.stl
24.0 x 24.0 x 34.2

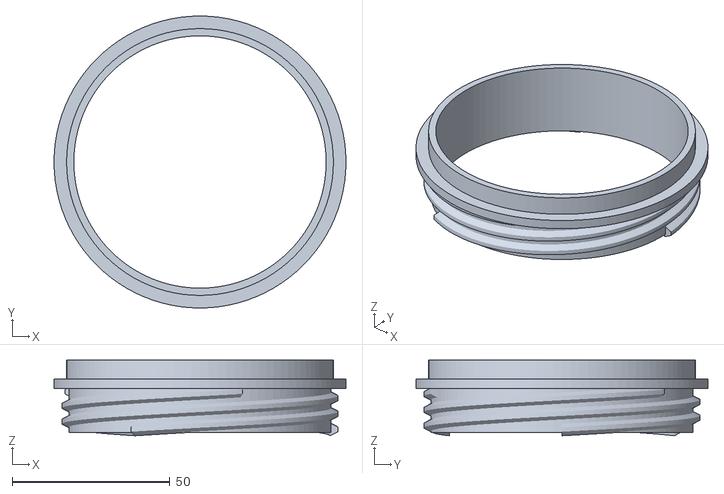
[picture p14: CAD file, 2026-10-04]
hardware/PWS_Waterraket_Test_Neusstomp_09.stl
92.7 x 92.7 x 24.0

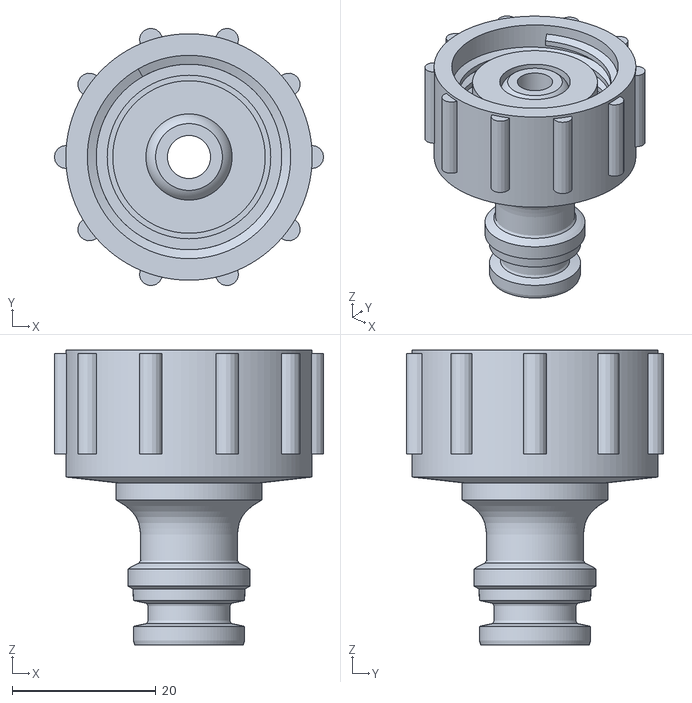
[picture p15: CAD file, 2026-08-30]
hardware/archief/PWS_Waterraket_NozzleGardena_06mm.stl
37.5 x 35.8 x 41.1

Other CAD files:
hardware/PWS_Waterraket_Recovery_Schot_A.stl
hardware/PWS_Waterraket_Test_Draadring.stl
hardware/archief/PWS_Waterraket_NozzleGardena_07mm.stl
hardware/PWS_Waterraket_Neus_Kegel.stl
hardware/PWS_Waterraket_Houder.3mf
hardware/PWS_Waterraket_Neus_Elliptisch.stl
hardware/PWS_Waterraket_Neus_Ogief.stl
hardware/PWS_Waterraket_NozzleLijm_04mm.stl
hardware/PWS_Waterraket_NozzleLijm_05mm.stl
hardware/PWS_Waterraket_NozzleLijm_06mm.stl
hardware/PWS_Waterraket_NozzleLijm_07mm.stl
hardware/PWS_Waterraket_NozzleLijm_08mm.stl
hardware/PWS_Waterraket_NozzleLijm_09mm.stl
hardware/PWS_Waterraket_NozzleOpzet_04mm.stl
hardware/PWS_Waterraket_NozzleOpzet_05mm.stl
hardware/PWS_Waterraket_NozzleOpzet_06mm.stl
hardware/PWS_Waterraket_NozzleOpzet_07mm.stl
hardware/PWS_Waterraket_NozzleOpzet_08mm.stl
hardware/PWS_Waterraket_NozzleOpzet_09mm.stl
hardware/PWS_Waterraket_NozzleSteunring_04mm.stl
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

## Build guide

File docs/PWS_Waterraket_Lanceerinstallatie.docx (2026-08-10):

# Lanceerinstallatie waterraket

Bouwtekening en onderdelenlijst – Split-collar cable-tie ontwerp met manometer en aftapventiel.

## 1 Ontwerp

De installatie is gebaseerd op de Clark cable-tie launcher: kabelbinders (cable ties) rondom de flessenhals grijpen de flens, en een in twee helften gedeelde kraag houdt ze vast. Via een trekkoord trek je die kraag vanaf veilige afstand omlaag, waarna de raket loskomt. Het cable-tie-principe is bedacht door Ian Clark en geldt als het de-facto standaardontwerp omdat het betrouwbaar en eenvoudig te maken is. De release past op een standaard Gardena-koppeling, zodat je dezelfde kop met meerdere launchers kunt gebruiken.

De luchtkant heeft drie functies die het geheel veilig en meetbaar maken: een terugslagklep houdt de druk in de fles als je de pomp losneemt, een manometer leest de werkelijke flesdruk, en een aftap-/ontluchtingskraan laat de druk bij een misser gecontroleerd ontsnappen.

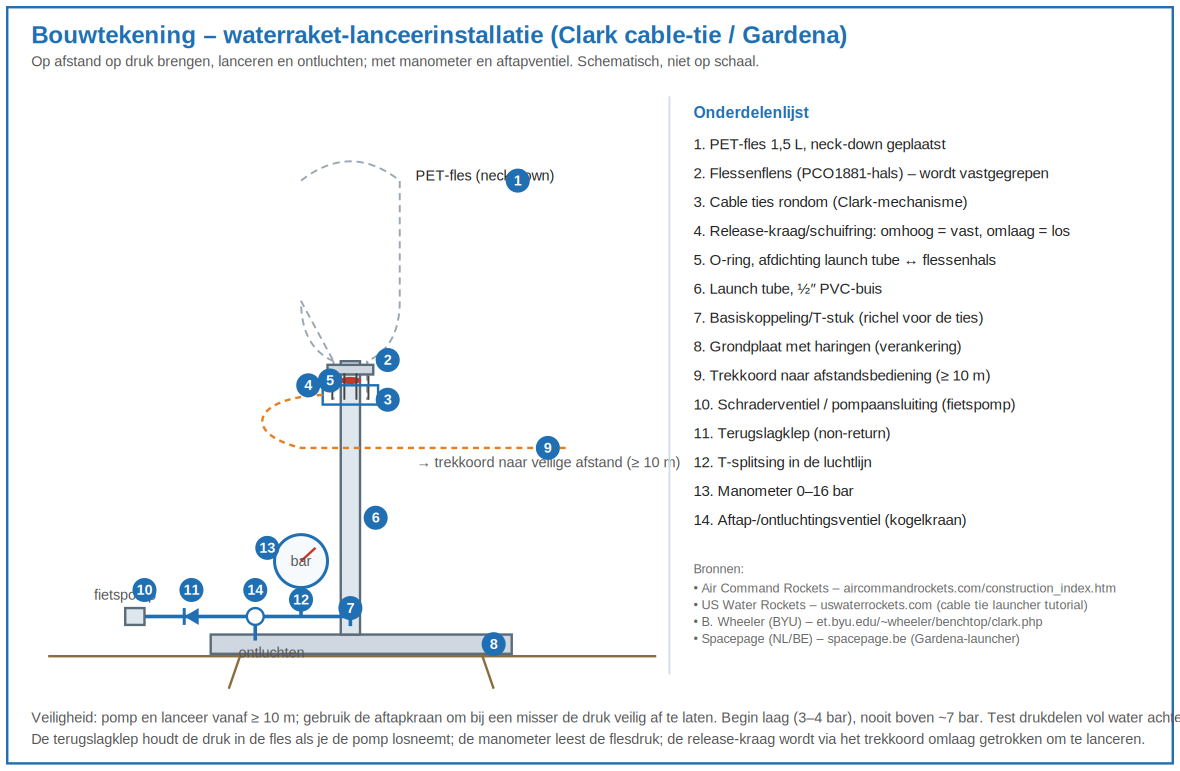
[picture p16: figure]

Figuur 1 – Schematische bouwtekening van de lanceerinstallatie (niet op schaal).

## 2 Onderdelenlijst

Nr | Onderdeel | Specificatie | Aantal | Waar (NL)
2/3 | Cable ties | zware nylon ~4,8 mm (of RVS) | 6–8 | bouwmarkt
4 | Gedeelde kraag (twee helften) | PVC-buis over de ties, in de lengte doormidden gezaagd | 1 | bouwmarkt
5 | O-ring | passend bij de launch-tube-diameter | 1 | seal-shop / eigen voorraad
6 | Launch tube | ½″ PVC-buis, ~25–30 cm | 1 | bouwmarkt
7 | ½″ PVC female-female koppeling | richel waar de ties tegenaan grijpen | 1 | bouwmarkt
– | PVC T-stukken/fittingen | voor de luchtmanifold | enkele | bouwmarkt
– | Zelfklemtang (locking pliers) | houdt de kraaghelften dicht; trekkoord aan het ontgrendellipje | 1 | gereedschapswinkel
13 | Manometer 0–16 bar | ¼″ schroefdraad | 1 | compressor-accessoires
11 | Terugslagklep (non-return) | ¼″ of slangmaat | 1 | pneumatiek/compressor
14 | Kogelkraan (aftap/ontluchten) | ¼″ | 1 | bouwmarkt
10 | Schraderventiel/pompkoppeling | autobandventiel of pompnippel | 1 | fiets/auto
– | Pneumatiek-/vinylslang + klemmen | ~10 m (pompen op afstand) | 1 | bouwmarkt
– | PTFE-tape | schroefdraad afdichten | 1 | bouwmarkt
8 | Grondplaat | multiplex ~18 mm of stalen plaat | 1 | bouwmarkt
8 | Haringen/grondpennen | verankering | 2–4 | kampeerwinkel
9 | Trekkoord | dun nylon touw, ~10 m | 1 | bouwmarkt

## 3 Bouwdetails

- De ½″ female-female PVC-koppeling vormt de basis/richel waar de cable ties tegenaan grijpen, zodat ze onder druk niet wegglijden.
- Plaats de O-ring zo dat de launch tube tegen de flessenhals afdicht; een dun laagje siliconenvet houdt de afdichting soepel (geen minerale olie bij Viton).
- Volgorde luchtlijn vanaf de fles: aftap/ontluchtingskraan en manometer aan de flessenzijde, daarna de terugslagklep, dan de pomp – zo beschermt de terugslagklep de pomp en leest de manometer de flesdruk.
- Maak het platform met haringen aan de grond vast en houd de lanceerhoek constant voor reproduceerbare metingen.

## 4 Veiligheid

- Breng op druk en lanceer vanaf ≥ 10 m, via het trekkoord.
- Begin laag (3–4 bar) en ga nooit boven ~7 bar.
- Gebruik bij een misser de aftapkraan om de druk veilig af te laten vóórdat je naar de raket loopt.
- Draag een veiligheidsbril en test 3D-geprinte of versterkte drukdelen eerst vol water achter een afscherming.

## 5 Bronnen

Air Command Rockets – tutorial-index (Clark cable-tie, Gardena release, drukontlast/terugslagklep) – http://aircommandrockets.com/construction_index.htm

Air Command Rockets – Clark cable-tie launcher – http://www.aircommandrockets.com/construction_9.htm

US Water Rockets – Cable Tie Launcher tutorial (½″ PVC, female-female koppeling als richel) – http://www.uswaterrockets.com/construction_&_tutorials/cable_tie_launcher/tutorial.htm

B. Wheeler (BYU) – The Clark cable-tie launcher (principe, herkomst, lucht-geactiveerde release) – https://www.et.byu.edu/~wheeler/benchtop/clark.php

Spacepage (NL/BE) – Gardena-lanceerplatform met ontkoppelsysteem – https://www.spacepage.be/artikelen/waterraketten/lanceerplatformen-launchers/

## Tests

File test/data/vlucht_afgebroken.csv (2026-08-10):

# vlucht 3 | gestart 2026-08-09 14:52
t_ms | hoogte_m | druk_hPa | temp_C | ax_g | ay_g | az_g
-100 | 0.04 | 1013.40 | 21.3 | 0.02 | 0.01 | 1.00
-80 | 0.00 | 1013.40 | 21.3 | 0.02 | -0.03 | 1.01
-60 | 0.08 | 1013.39 | 21.3 | -0.02 | 0.00 | 1.02
-40 | -0.02 | 1013.40 | 21.2 | -0.03 | -0.01 | 0.99
-20 | 0.03 | 1013.40 | 21.3 | 0.02 | 0.00 | 0.98
0 | 0.02 | 1013.40 | 21.2 | -0.01 | 0.29 | 1.00
20 | -0.06 | 1013.41 | 21.1 | -0.33 | 0.13 | 9.65
40 | 0.07 | 1013.39 | 21.3 | 0.04 | -0.19 | 11.76
60 | 0.09 | 1013.39 | 21.3 | 0.31 | -0.26 | 12.94
80 | 0.22 | 1013.37 | 21.3 | -0.08 | -0.08 | 13.58
100 | 0.47 | 1013.34 | 21.3 | -0.35 | 0.26 | 13.86
120 | 0.64 | 1013.32 | 21.3 | 0.13 | 0.26 | 13.85

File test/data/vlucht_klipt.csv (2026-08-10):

# vlucht 5 | gestart 2026-08-09 15:28
t_ms | hoogte_m | druk_hPa | temp_C | ax_g | ay_g | az_g
-600 | 0.01 | 1013.40 | 21.2 | -0.02 | -0.02 | 0.98
-580 | -0.10 | 1013.41 | 21.3 | 0.00 | 0.00 | 0.98
-560 | -0.00 | 1013.40 | 21.3 | 0.02 | 0.00 | 0.99
-540 | 0.09 | 1013.39 | 21.3 | 0.01 | -0.00 | 1.00
-520 | 0.13 | 1013.38 | 21.4 | 0.00 | 0.01 | 1.00
-500 | 0.09 | 1013.39 | 21.3 | -0.00 | 0.03 | 1.02
-480 | -0.02 | 1013.40 | 21.2 | 0.03 | -0.00 | 1.01
-460 | 0.08 | 1013.39 | 21.3 | -0.03 | 0.01 | 1.02
-440 | 0.03 | 1013.40 | 21.3 | 0.01 | 0.01 | 0.98
-420 | -0.04 | 1013.40 | 21.3 | -0.03 | 0.02 | 1.01
-400 | -0.02 | 1013.40 | 21.3 | 0.02 | -0.02 | 1.01
-380 | 0.12 | 1013.39 | 21.3 | 0.01 | 0.00 | 1.00
-360 | 0.01 | 1013.40 | 21.4 | -0.02 | -0.03 | 0.97
-340 | 0.09 | 1013.39 | 21.3 | -0.00 | 0.03 | 0.98
-320 | -0.02 | 1013.40 | 21.3 | -0.00 | 0.01 | 0.95
-300 | -0.07 | 1013.41 | 21.3 | -0.01 | -0.00 | 0.99
-280 | 0.07 | 1013.39 | 21.3 | -0.03 | -0.01 | 1.01
-260 | 0.15 | 1013.38 | 21.4 | 0.01 | -0.02 | 1.01
-240 | -0.03 | 1013.40 | 21.4 | 0.02 | 0.02 | 0.99
-220 | -0.03 | 1013.40 | 21.3 | -0.03 | 0.01 | 0.99
-200 | 0.05 | 1013.39 | 21.2 | 0.02 | 0.01 | 0.99
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

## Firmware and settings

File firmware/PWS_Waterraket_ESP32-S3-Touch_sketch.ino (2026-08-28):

/*
  Waterraket-vluchtcomputer met touch-UI  -  PWS natuurkunde
  ==============================================================
  Bord     : Waveshare ESP32-S3-Touch-LCD-1.69 (ESP32-S3, 240x280 ST7789V2,
             CST816 touch, QMI8658 IMU)
  Extra    : BMP388 barometer (los, via I2C bijgeprikt)  -> de HOOGTEMETING
  UI       : HOME-scherm met stats + START-knop  ->  live vlucht  ->
             RESULTAAT-scherm met stats + VERZEND-knop (opent wifi om te downloaden)

  ---- BENODIGDE LIBRARIES (Arduino IDE -> Bibliotheken beheren) ----
    - "GFX Library for Arduino"   (Arduino_GFX, door moononournation)  -> LCD
    - "SensorLib"                 (door lewisxhe)  -> QMI8658 IMU EN CST816 touch
    - "Adafruit BMP3XX Library"   (+ "Adafruit Unified Sensor" + "Adafruit BusIO")
    WiFi / WebServer / LittleFS / Wire zitten in de ESP32-Arduino board-package.

  ---- BOARD-INSTELLINGEN (Tools) ----
    Board: "ESP32S3 Dev Module" | PSRAM: "OPI PSRAM" | USB CDC On Boot: "Enabled"

  ---- LET OP: verifieer de pinnen/offsets met de Waveshare-wiki van jouw revisie ----
    Blijft het scherm zwart of staat het verschoven? Pas LCD_*-pinnen/offsets aan.
    Reageert de touch niet of gespiegeld? Pas TP_*-pinnen en TOUCH_FLIP_* aan.
    Fallback: de fysieke BOOT-knop (GPIO0) werkt altijd als START-knop.

  ---- ACCU (belangrijk) ----
    3,7V LiPo met MX1.25 (1,25 mm) stekker. CONTROLEER DE POLARITEIT tegen de
    markering op het bord VOORDAT je insteekt; omgekeerd kan het bord beschadigen.
    Laden via USB-C (ETA6098-lader op het bord).
    Op accu: sluit de accu aan, druk op de PWR-knop, daarna houdt de SYS_EN-latch
    hieronder de voeding vast.
*/

// ====================== CONFIG ======================
// --- I2C (BMP388 + onboard QMI8658 + CST816 touch delen deze bus) ---
#define I2C_SDA      11
#define I2C_SCL      10
#define BMP_ADDR     0x77      // BMP388: 0x77 of 0x76

// --- touch (CST816) ---
#define TP_RST       13        // CST816 reset  (schematic: TP_RST = GPIO13)
#define TP_INT       14        // CST816 interrupt (schematic: TP_INT = GPIO14)
#define TOUCH_FLIP_X 0
#define TOUCH_FLIP_Y 0

// --- LCD (ST7789V2 via SPI) ---
#define LCD_SCLK     6
#define LCD_MOSI     7
#define LCD_MISO    -1
#define LCD_CS       5
#define LCD_DC       4
#define LCD_RST      8
#define LCD_BL      15
#define LCD_W        240
#define LCD_H        280
#define LCD_OFFX     0
// 20 is juist voor dit paneel (met 0 loopt de titel van het scherm).
// De ~22 px afwijking zit in de TOUCH, niet in het beeld: die corrigeer je
// met het ijkscherm (INFO -> lang BOOT -> lang BOOT).
#define LCD_OFFY     20

// --- buzzer (optioneel; pin verifiëren) ---
#define USE_BUZZER   0
#define BUZZER_PIN   42   // onboard buzzer (officiele documentatie)

// --- fysieke knop als START-fallback ---
#define BOOT_BTN     0

// --- voedingslatch accu ---
// Het bord start NIET vanzelf op de accu: de PWR-knop geeft de accuvoeding
// kortstondig vrij, daarna moet de firmware SYS_EN hoog houden. Zonder deze
// latch valt de voeding weg zodra je PWR loslaat (op USB merk je hier niets van).
// Officiele Waveshare-documentatie voor dit bord (SKU 27350):
//   SYS_EN = GPIO41 (houdt de accuvoeding vast), SYS_OUT = GPIO40 (PWR-knop).
// Werkt de accuvoeding niet, probeer dan BOARD_ALT 1 (35/36).
#define BOARD_ALT    0
#if BOARD_ALT
  #define SYS_EN     35
  #define SYS_OUT    36
#else
  #define SYS_EN     41
  #define SYS_OUT    40
#endif

// --- gedrag ---
#define SAMPLE_HZ       50
#define LAUNCH_RISE_M   3.0
#define LAND_ALT_M      2.0
#define LAND_WINDOW_S   3
#define MAX_LOG_S       30

// --- parachute (servogrendel op de zijdeur) ---
#define SERVO_PIN       18
#define SERVO_DICHT     35     // graden: hoorn in de grendellip
#define SERVO_OPEN      125    // graden: hoorn weg, deur klapt open
#define DEPLOY_DROP_M   1.5    // zoveel onder het maximum = voorbij het apogeum
#define DEPLOY_MIN_M    8.0    // niet openen onder deze hoogte (misdetectie)
#define DEPLOY_MAX_S    12.0   // noodvangnet: altijd openen na deze vluchttijd
#define SERVO_NA_MS     4000   // servo daarna stroomloos: scheelt stroom en gepiep

const char* AP_SSID = "Waterraket";
const char* AP_PASS = "raket1234";
const char* INDEXPAD = "/vluchten.csv";   // overzicht van alle vluchten
int  flightNo = 0;                        // nummer van de huidige vlucht
char logPad[24] = "/flight_1.csv";        // logbestand van de huidige vlucht
const uint32_t SAMPLE_US = 1000000UL / SAMPLE_HZ;

// ====================== INCLUDES ======================
#include <Wire.h>
#include <math.h>
#include <Adafruit_BMP3XX.h>
#include <Adafruit_BME680.h>   // voor de CJMCU-680 (BME680)
#include <SensorQMI8658.hpp>
#include <TouchDrv.hpp>        // (TouchDrvCSTXXX.hpp is deprecated)
#include <LittleFS.h>
#include <WiFi.h>
#include <WebServer.h>
#include <Arduino_GFX_Library.h>

// --- types boven alle functies ---
// De Arduino IDE genereert zelf functieprototypes en zet die bovenaan het
// bestand. Staat een struct lager, dan kent dat prototype het type nog niet
// ("'Klok' does not name a type"). Daarom hier.
struct Klok { int jaar, maand, dag, uur, minuut, sec; bool geldig; };

// --- kleuren (RGB565), eigen definities zodat ze niet van de library-versie afhangen ---
#define COL_BLACK     0x0000
#define COL_WHITE     0xFFFF
#define COL_CYAN      0x07FF
#define COL_GREEN     0x07E0
#define COL_BLUE      0x001F
#define COL_YELLOW    0xFFE0
#define COL_MAGENTA   0xF81F
#define COL_ORANGE    0xFD20
#define COL_DARKGREY  0x7BEF

// ====================== OBJECTEN ======================
Adafruit_BMP3XX bmp;
Adafruit_BME680  bme;
// welke druksensor is er gevonden?
enum BaroType { BARO_GEEN, BARO_BMP388, BARO_BMP390, BARO_BME680 };
BaroType baro = BARO_GEEN;
uint8_t  baroAdr = 0;
SensorQMI8658   qmi;
TouchDrvCSTXXX  touch;
WebServer       server(80);
File            logFile;
bool touchOK = false;

Arduino_DataBus *bus = new Arduino_ESP32SPI(LCD_DC, LCD_CS, LCD_SCLK, LCD_MOSI, LCD_MISO);
Arduino_GFX *gfx = new Arduino_ST7789(bus, LCD_RST, 0, true, LCD_W, LCD_H,
                                      LCD_OFFX, LCD_OFFY, LCD_OFFX, LCD_OFFY);

// ====================== TOESTAND ======================
enum State { HOME, INFO, TOUCHTEST, CALIB, ARMED, LOGGING, RESULT, SENDING };
State state = HOME;
bool entered = false;            // is het huidige scherm al getekend?

float p0 = 1013.25;
float curAlt = 0, maxAlt = 0;
float ax = 0, ay = 0, az = 0, curG = 0, maxG = 0;
uint32_t tStart = 0, lastSample = 0, flightMs = 0;
uint32_t samples = 0;
int landCount = 0, uiCount = 0;
bool haveFlight = false;
bool touchWasDown = false, bootWasDown = false;
int  lastTx = -1, lastTy = -1;   // laatste aanraakcoordinaten (na correctie)
int  rawTx = -1, rawTy = -1;     // laatste RUWE aanraakcoordinaten
uint32_t tapCount = 0;           // hoeveel aanrakingen ooit gezien
// touch-kalibratie: scherm = a * ruw + b  (1,0 / 0 = ongecorrigeerd)
// Gemeten op dit bord: de touch rapporteert y ~22 px HOGER dan waar je tikt
// (kruis getekend op y=140 werd twee keer gemeld als 162). Dat is een vaste
// verschuiving, geen schaalfout, dus corrigeren we met -22 en schaal 1,0.
float calAx = 1.0, calBx = 0.0, calAy = 1.0, calBy = -22.0;
const char* CALPATH = "/touchcal2.txt";   // nieuwe naam: oude ijking vervalt

// ====================== KNOPPEN ======================
struct Btn { int x, y, w, h; const char* label; uint16_t col; };
// Knoppen blijven boven y=230: dat is het gebied dat de touch betrouwbaar haalt.
Btn BTN_START  = { 22, 146, 92, 52, "START",   COL_GREEN };
Btn BTN_INFO   = { 126, 146, 92, 52, "INFO",    COL_BLUE };
Btn BTN_CANCEL = { 30, 190, 180, 46, "ANNULEER", COL_DARKGREY };
Btn BTN_SEND   = { 24, 190, 92, 46, "VERZEND", COL_BLUE };
Btn BTN_NEW    = { 124, 190, 92, 46, "NIEUW",  COL_DARKGREY };
Btn BTN_BACK   = { 30, 190, 180, 46, "TERUG",   COL_DARKGREY };

void drawBtn(Btn b) {
  gfx->fillRoundRect(b.x, b.y, b.w, b.h, 10, b.col);
  gfx->setTextColor(b.col == COL_DARKGREY ? COL_WHITE : COL_BLACK);
  int sz = 3;                                   // kleiner als het niet past
  while (sz > 1 && (int)strlen(b.label) * 6 * sz > b.w - 10) sz--;
  int tw = (int)strlen(b.label) * 6 * sz;
  gfx->setTextSize(sz);
  gfx->setCursor(b.x + (b.w - tw) / 2, b.y + (b.h - 8 * sz) / 2);
  gfx->print(b.label);
}
bool hit(Btn b, int x, int y) { return x >= b.x && x <= b.x + b.w && y >= b.y && y <= b.y + b.h; }

// nieuwe aanraking (opgaande flank); true + coords bij een verse tik
bool getTap(int &gx, int &gy) {
  bool tap = false;
  if (touchOK) {
    int16_t x[1], y[1];
    uint8_t n = touch.getPoint(x, y, 1);
    bool down = (n > 0);
    if (down && !touchWasDown) {
      gx = x[0]; gy = y[0];
#if TOUCH_FLIP_X
      gx = LCD_W - 1 - gx;
#endif
#if TOUCH_FLIP_Y
      gy = LCD_H - 1 - gy;
#endif
      tap = true;
      rawTx = gx; rawTy = gy;                       // ruw bewaren voor kalibratie
      gx = (int)(calAx * gx + calBx);               // kalibratie toepassen
      gy = (int)(calAy * gy + calBy);
      lastTx = gx; lastTy = gy; tapCount++;
      Serial.printf("touch: ruw x=%d y=%d -> scherm x=%d y=%d\n", rawTx, rawTy, gx, gy);
    }
    touchWasDown = down;
  }
  return tap;
}
// fysieke BOOT-knop als START-fallback
bool bootTap() {
  bool down = (digitalRead(BOOT_BTN) == LOW);
  bool tap = (down && !bootWasDown);
  bootWasDown = down;
  return tap;
}

// ====================== SENSOREN ======================
uint8_t leesReg(uint8_t adr, uint8_t reg) {
  Wire.beginTransmission(adr);
  Wire.write(reg);
  if (Wire.endTransmission(false) != 0) return 0xFF;
  if (Wire.requestFrom(adr, (uint8_t)1) != 1) return 0xFF;
  return Wire.read();
}

// ====================== RTC (PCF85063 op 0x51) ======================
// Rechtstreeks via I2C: de registers liggen vast in het datasheet en kunnen
// niet met een library-versie meeveranderen.
#define RTC_ADDR 0x51
void schrijfReg(uint8_t adr, uint8_t reg, uint8_t val) {
  Wire.beginTransmission(adr); Wire.write(reg); Wire.write(val); Wire.endTransmission();
}
uint8_t bcd2dec(uint8_t b) { return (b >> 4) * 10 + (b & 0x0F); }
uint8_t dec2bcd(uint8_t d) { return ((d / 10) << 4) | (d % 10); }

Klok leesKlok() {
  Klok k;
  uint8_t s = leesReg(RTC_ADDR, 0x04);
  k.geldig = !(s & 0x80);          // bit 7 = oscillator gestopt: tijd onbetrouwbaar
  k.sec    = bcd2dec(s & 0x7F);
  k.minuut = bcd2dec(leesReg(RTC_ADDR, 0x05) & 0x7F);
  k.uur    = bcd2dec(leesReg(RTC_ADDR, 0x06) & 0x3F);
  k.dag    = bcd2dec(leesReg(RTC_ADDR, 0x07) & 0x3F);
  k.maand  = bcd2dec(leesReg(RTC_ADDR, 0x09) & 0x1F);
  k.jaar   = 2000 + bcd2dec(leesReg(RTC_ADDR, 0x0A));
  return k;
}
void zetKlok(int j, int mnd, int d, int u, int mi, int se) {
  schrijfReg(RTC_ADDR, 0x04, dec2bcd(se));   // schrijven wist meteen de OS-vlag
  schrijfReg(RTC_ADDR, 0x05, dec2bcd(mi));
  schrijfReg(RTC_ADDR, 0x06, dec2bcd(u));
  schrijfReg(RTC_ADDR, 0x07, dec2bcd(d));
  schrijfReg(RTC_ADDR, 0x09, dec2bcd(mnd));
  schrijfReg(RTC_ADDR, 0x0A, dec2bcd(j - 2000));
}
void klokUitCompileertijd() {                // eenmalige startwaarde
  char m[4]; int d, j, u, mi, se;
  sscanf(__DATE__, "%3s %d %d", m, &d, &j);
  sscanf(__TIME__, "%d:%d:%d", &u, &mi, &se);
  const char* en = "JanFebMarAprMayJunJulAugSepOctNovDec";
  const char* pos = strstr(en, m);
  int mnd = pos ? (int)(pos - en) / 3 + 1 : 1;
  zetKlok(j, mnd, d, u, mi, se);
}
String tijdTekst() {
  Klok k = leesKlok();
  char b[24];
  snprintf(b, sizeof(b), "%04d-%02d-%02d %02d:%02d", k.jaar, k.maand, k.dag, k.uur, k.minuut);
  return String(b);
}

// ====================== PARACHUTE-SERVO ======================
// Rechtstreeks via LEDC (hardware-PWM), zonder servo-library: 50 Hz, 16 bit.
// Een standaardservo wil 1,0 ms (0 graden) tot 2,0 ms (180 graden) puls.
#define SERVO_KANAAL 4
bool servoActief = false;
uint32_t servoTot = 0;          // millis waarop de servo weer stil gezet wordt
bool chuteUit = false;          // is de deur deze vlucht al geopend?

void servoHoek(int graden) {
  graden = constrain(graden, 0, 180);
  uint32_t us = 1000 + (uint32_t)(graden * 1000L / 180);      // 1000..2000 us
  uint32_t duty = (uint32_t)((uint64_t)us * 65535 / 20000);   // periode 20 ms
  ledcWrite(SERVO_PIN, duty);
  servoActief = true;
  servoTot = millis() + SERVO_NA_MS;
}
void servoUit() {                       // stroomloos: geen brom, geen verbruik
  if (servoActief && millis() > servoTot) { ledcWrite(SERVO_PIN, 0); servoActief = false; }
}
void chuteGrendel() { servoHoek(SERVO_DICHT); chuteUit = false; }
void chuteOpen()    { servoHoek(SERVO_OPEN);  chuteUit = true; beep(120); }


// ====================== VLUCHTBESTANDEN ======================
// Elke vlucht krijgt een eigen bestand: /flight_1.csv, /flight_2.csv, ...
int hoogsteVluchtnummer() {
  int hoogste = 0;
  File dir = LittleFS.open("/");
  if (!dir) return 0;
  File f = dir.openNextFile();
  while (f) {
    String n = f.name();
    if (!n.startsWith("/")) n = "/" + n;     // core 2.x geeft pad, 3.x alleen naam
    if (n.startsWith("/flight_") && n.endsWith(".csv")) {
      int nr = n.substring(8, n.length() - 4).toInt();
      if (nr > hoogste) hoogste = nr;
    }
    f = dir.openNextFile();
  }
  return hoogste;
}

float relAltitude(float pres_hPa) { return 44330.0 * (1.0 - pow(pres_hPa / p0, 0.1903)); }

bool readBaro(float &alt, float &pres, float &temp) {
  if (baro == BARO_BMP388 || baro == BARO_BMP390) {   // zelfde library en API
    if (!bmp.performReading()) return false;
    pres = bmp.pressure / 100.0; temp = bmp.temperature;
  } else if (baro == BARO_BME680) {
    if (!bme.performReading()) return false;
    pres = bme.pressure / 100.0; temp = bme.temperature;
  } else {
    return false;
  }
  alt = relAltitude(pres);
  return true;
}
const char* baroNaam() {
  switch (baro) {
    case BARO_BMP388: return "BMP388";
    case BARO_BMP390: return "BMP390";      // o.a. DFRobot BMP390L
    case BARO_BME680: return "BME680";
    default:          return "geen";
  }
}
void readImu() {
  if (qmi.getDataReady()) {
    qmi.getAccelerometer(ax, ay, az);
    curG = sqrt(ax * ax + ay * ay + az * az);
    if (curG > maxG) maxG = curG;
  }
}
void beep(int ms) {
#if USE_BUZZER
  digitalWrite(BUZZER_PIN, HIGH); delay(ms); digitalWrite(BUZZER_PIN, LOW);
#endif
}
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
void loop() {
  servoUit();          // servo stil zetten als hij lang genoeg gestuurd is

  int gx = 0, gy = 0;
  float alt, pres, temp;

  switch (state) {

    case HOME: {
      if (!entered) { screenHome(); entered = true; }
      bool go = false, wantInfo = false;
      if (getTap(gx, gy)) {
        if (hit(BTN_START, gx, gy))     go = true;
        else if (hit(BTN_INFO, gx, gy)) wantInfo = true;
      }
      // BOOT-knop als touch niet werkt: kort = INFO, lang (>1,2 s) = START
      static uint32_t bootDown = 0;
      bool bd = (digitalRead(BOOT_BTN) == LOW);
      if (bd && bootDown == 0) bootDown = millis();
      if (!bd && bootDown) {
        uint32_t held = millis() - bootDown; bootDown = 0;
        if (held > 1200) go = true; else wantInfo = true;
      }
      if (wantInfo) { state = INFO; entered = false; }
      else if (go) {
        title("KALIBREREN...", COL_WHITE);          // even feedback
        calibrate(); beep(80);
        state = ARMED; entered = false;
      }
      delay(30);
    } break;

    case INFO: {
      if (!entered) { screenInfo(); entered = true; }
      liveInfo();
      if (getTap(gx, gy) && hit(BTN_BACK, gx, gy)) { state = HOME; entered = false; }
      // BOOT: kort = terug, 1,2-3 s = deurtest (bankproef), >3 s = raaktest
      static uint32_t bootDownI = 0;
      bool bdi = (digitalRead(BOOT_BTN) == LOW);
      if (bdi && bootDownI == 0) bootDownI = millis();
      if (!bdi && bootDownI) {
        uint32_t held = millis() - bootDownI; bootDownI = 0;
        if (held > 3000) { state = TOUCHTEST; entered = false; }
        else if (held > 1200) {                    // deur open, 3 s later weer dicht
          gfx->fillRect(SAFE_M, 246, 190, 12, COL_BLACK);
          gfx->setTextSize(1); gfx->setTextColor(COL_MAGENTA);
          gfx->setCursor(SAFE_M, 248); gfx->print("deur OPEN");
          chuteOpen(); delay(3000); chuteGrendel();
          gfx->fillRect(SAFE_M, 246, 190, 12, COL_BLACK);
        } else { state = HOME; entered = false; }
      }
      delay(120);
    } break;

    case TOUCHTEST: {
      if (!entered) { screenTouchTest(); entered = true; }
      if (getTap(gx, gy)) drawCross(gx, gy);
      // BOOT: kort = terug, lang (>1,2 s) = ijken
      static uint32_t bootDownT = 0;
      bool bdt = (digitalRead(BOOT_BTN) == LOW);
      if (bdt && bootDownT == 0) bootDownT = millis();
      if (!bdt && bootDownT) {
        uint32_t held = millis() - bootDownT; bootDownT = 0;
        if (held > 4000) {                    // heel lang = kalibratie wissen
          calAx = 1.0; calBx = 0.0; calAy = 1.0; calBy = 0.0;
          LittleFS.remove(CALPATH);
          Serial.println("kalibratie gewist (ongecorrigeerd)");
          gfx->fillScreen(COL_BLACK); title("GEWIST", COL_ORANGE);
          delay(1200); entered = false;
        } else {
          state = (held > 1200) ? CALIB : HOME;
          entered = false;
        }
      }
      delay(30);
    } break;

    case CALIB: {
      static int step = 0;
      static int r1x = 0, r1y = 0;
      if (!entered) {
        step = 0;
        // tijdens het ijken ongecorrigeerd meten
        calAx = 1.0; calBx = 0.0; calAy = 1.0; calBy = 0.0;
        drawTarget(CAL_X1, CAL_Y1, "Punt 1 van 2");
        entered = true;
      }
      if (getTap(gx, gy)) {
        if (step == 0) {
          r1x = rawTx; r1y = rawTy; step = 1;
          delay(400);                      // dubbele tik voorkomen
          drawTarget(CAL_X2, CAL_Y2, "Punt 2 van 2");
        } else {
          int dxr = rawTx - r1x, dyr = rawTy - r1y;
          if (abs(dxr) > 20 && abs(dyr) > 20) {      // plausibel?
            calAx = (float)(CAL_X2 - CAL_X1) / dxr;
            calBx = CAL_X1 - calAx * r1x;
            calAy = (float)(CAL_Y2 - CAL_Y1) / dyr;
            calBy = CAL_Y1 - calAy * r1y;
            saveCal();
            gfx->fillScreen(COL_BLACK);
            title("GEIJKT", COL_GREEN);
            gfx->setTextSize(1); gfx->setTextColor(COL_WHITE);
            gfx->setCursor(SAFE_M, 120); gfx->print("Opgeslagen. Controleer met");
            gfx->setCursor(SAFE_M, 134); gfx->print("de raaktest.");
          } else {
            gfx->fillScreen(COL_BLACK);
            title("MISLUKT", COL_ORANGE);
            gfx->setTextSize(1); gfx->setTextColor(COL_WHITE);
            gfx->setCursor(SAFE_M, 120); gfx->print("Punten lagen te dicht bij");
            gfx->setCursor(SAFE_M, 134); gfx->print("elkaar. Probeer opnieuw.");
          }
          delay(2000);
          state = TOUCHTEST; entered = false;
        }
      }
      if (bootTap()) { state = HOME; entered = false; }
      delay(30);
    } break;

    case ARMED:
      if (!entered) { screenArmed(); entered = true; }
      if (readBaro(alt, pres, temp)) { curAlt = alt; if (alt > maxAlt) maxAlt = alt; }
      if (curAlt > LAUNCH_RISE_M) {              // lancering
        logFile = LittleFS.open(logPad, "a");
        tStart = millis(); lastSample = micros(); maxAlt = curAlt; samples = 0;
        beep(60); state = LOGGING; entered = false; break;
      }
      if (getTap(gx, gy) && hit(BTN_CANCEL, gx, gy)) { state = HOME; entered = false; }
      delay(20);
      break;

    case LOGGING:
      if (!entered) { screenLogging(); entered = true; }
      if (micros() - lastSample >= SAMPLE_US) {
        lastSample += SAMPLE_US;
        if (readBaro(alt, pres, temp)) curAlt = alt;
        readImu();
        uint32_t t = millis() - tStart;
        logFile.printf("%lu,%.2f,%.2f,%.1f,%.2f,%.2f,%.2f\n", t, curAlt, pres, temp, ax, ay, az);
        samples++;
        if (curAlt > maxAlt) maxAlt = curAlt;

        // --- parachute: open zodra we voorbij het apogeum zijn ---
        // Voorwaarden samen, zodat een enkele ruispiek de deur niet opent:
        // hoog genoeg, en de hoogte is al DEPLOY_DROP_M onder het maximum.
        if (!chuteUit) {
          float dt = (millis() - tStart) / 1000.0;
          bool voorbijTop = (maxAlt > DEPLOY_MIN_M) && (curAlt < maxAlt - DEPLOY_DROP_M);
          bool noodklok   = dt > DEPLOY_MAX_S;          // vangnet als detectie faalt
          if (voorbijTop || noodklok) {
            chuteOpen();
            Serial.printf("parachute op t=%.1f s, h=%.1f m (max %.1f) %s\n",
                          dt, curAlt, maxAlt, noodklok ? "[noodklok]" : "[apogeum]");
          }
        }
        if (curAlt < LAND_ALT_M && maxAlt > LAUNCH_RISE_M) landCount++; else landCount = 0;
        bool landed  = landCount > (LAND_WINDOW_S * SAMPLE_HZ);
        bool timeout = (millis() - tStart) > (MAX_LOG_S * 1000UL);
        if (landed || timeout) {
          logFile.close(); flightMs = millis() - tStart; haveFlight = true;
          File idx = LittleFS.open(INDEXPAD, "a");     // regel in het overzicht
          if (idx) {
            idx.printf("%d;%s;%.1f;%.1f;%.1f\n", flightNo, tijdTekst().c_str(),
                       maxAlt, maxG, flightMs / 1000.0);
            idx.close();
          }
          beep(200); state = RESULT; entered = false; break;
        }
        if (++uiCount >= 10) { uiCount = 0; liveLogging(); }   // scherm ~5 Hz, log 50 Hz
      }
      break;

    case RESULT:
      if (!entered) { screenResult(); entered = true; }
      if (getTap(gx, gy)) {
        if (hit(BTN_SEND, gx, gy)) { startAP(); state = SENDING; entered = false; }
        else if (hit(BTN_NEW, gx, gy)) { state = HOME; entered = false; }
      }
      delay(30);
      break;

    case SENDING:
      if (!entered) { screenSending(); entered = true; }
      server.handleClient();
      if (getTap(gx, gy) && hit(BTN_BACK, gx, gy)) { state = RESULT; entered = false; }
      break;
  }
}

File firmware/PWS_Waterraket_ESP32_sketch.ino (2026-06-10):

/*
  Waterraket-vluchtcomputer  -  PWS natuurkunde
  --------------------------------------------------------------
  Board    : Seeed XIAO ESP32-S3   (Arduino-ESP32 core)
  Sensoren : BMP280 barometer (niveau 1)
             + optioneel MPU6050 IMU (niveau 2, zet USE_IMU op 1)
  Werking  : 1) kalibreren op de grond (nuldruk bepalen)
             2) lancering detecteren (hoogte stijgt boven drempel)
             3) loggen op 50 Hz naar intern flashgeheugen (LittleFS)
             4) apogeum bepalen (hoogste gemeten hoogte)
             5) landing detecteren (laag + stabiel) of time-out
             6) wifi-accesspoint openen -> data als CSV downloaden

  Libraries (Arduino IDE -> Tools -> Bibliotheken beheren):
    - Adafruit BMP280 Library
    - Adafruit Unified Sensor
    - Adafruit MPU6050        (alleen bij niveau 2)
  De ESP32-, WiFi-, WebServer- en LittleFS-onderdelen zitten in de
  Arduino-ESP32 board-package.
*/

#include <Wire.h>
#include <Adafruit_BMP280.h>
#include <LittleFS.h>
#include <WiFi.h>
#include <WebServer.h>

// ----------------------- instellingen -----------------------
#define USE_IMU        0       // 0 = niveau 1 (alleen barometer), 1 = niveau 2 (+ MPU6050)
#define SAMPLE_HZ      50      // logfrequentie (Hz)
#define LAUNCH_RISE_M  3.0     // hoogtestijging (m) die een lancering aanduidt
#define LAND_ALT_M     2.0     // hoogte (m) waaronder de raket 'laag' is
#define LAND_WINDOW_S  3       // stabiele periode (s) die een landing aanduidt
#define MAX_LOG_S      30      // veiligheidslimiet: maximale logduur (s)

const char* AP_SSID = "Waterraket";   // naam wifi-netwerk na de vlucht
const char* AP_PASS = "raket1234";    // wachtwoord (minimaal 8 tekens)

const char* LOGPATH  = "/flight.csv";
const uint32_t SAMPLE_US = 1000000UL / SAMPLE_HZ;

// ----------------------- objecten -----------------------
Adafruit_BMP280 bmp;
#if USE_IMU
  #include <Adafruit_MPU6050.h>
  Adafruit_MPU6050 mpu;
#endif
WebServer server(80);
File logf;

// ----------------------- toestand -----------------------
enum State { ARMED, LOGGING, LANDED };
State state = ARMED;

float p0      = 1013.25;  // basisdruk op de grond (hPa), in calibrate() bepaald
float maxAlt  = 0;        // hoogste gemeten hoogte = apogeum (m)
uint32_t tStart    = 0;   // starttijd van de logging (ms)
uint32_t lastSample = 0;  // micros van de laatste sample
int landCount = 0;        // teller voor landingsdetectie

// hoogte t.o.v. de grond, uit de barometrische formule
float relAltitude(float pres_hPa) {
  return 44330.0 * (1.0 - pow(pres_hPa / p0, 0.1903));
}

// XIAO-LED is actief-laag: 0 = uit, 1 = aan
void led(int on) { digitalWrite(LED_BUILTIN, on ? LOW : HIGH); }

void calibrate() {
  float sum = 0;
  for (int i = 0; i < 50; i++) { sum += bmp.readPressure() / 100.0; delay(20); }
  p0 = sum / 50.0;        // gemiddelde gronddruk over ~1 s
  maxAlt = 0;
  // logbestand (her)aanmaken met kolomkoppen
  logf = LittleFS.open(LOGPATH, "w");
#if USE_IMU
  logf.println("t_ms,hoogte_m,druk_hPa,temp_C,ax_ms2,ay_ms2,az_ms2");
#else
  logf.println("t_ms,hoogte_m,druk_hPa,temp_C");
#endif
  logf.close();
}

void startAP() {
  WiFi.mode(WIFI_AP);
  WiFi.softAP(AP_SSID, AP_PASS);
  server.on("/", []() {
    String h = "<h2>Waterraket - vluchtdata</h2>";
    h += "<p>Apogeum: " + String(maxAlt, 1) + " m</p>";
    h += "<p><a href='/flight.csv'>Download CSV</a></p>";
    server.send(200, "text/html", h);
  });
  server.on("/flight.csv", []() {
    File f = LittleFS.open(LOGPATH, "r");
    server.streamFile(f, "text/csv");
    f.close();
  });
  server.begin();
}

void setup() {
  pinMode(LED_BUILTIN, OUTPUT);
  Wire.begin();                 // XIAO ESP32-S3: SDA = D4, SCL = D5
  LittleFS.begin(true);

  if (!bmp.begin(0x76)) bmp.begin(0x77);   // BMP280 op adres 0x76 of 0x77
  bmp.setSampling(Adafruit_BMP280::MODE_NORMAL,
                  Adafruit_BMP280::SAMPLING_X2,
                  Adafruit_BMP280::SAMPLING_X16,
                  Adafruit_BMP280::FILTER_X4,
                  Adafruit_BMP280::STANDBY_MS_1);
#if USE_IMU
  mpu.begin();                              // MPU6050 op adres 0x68
  mpu.setAccelerometerRange(MPU6050_RANGE_16_G);
#endif

  calibrate();                  // bepaal nuldruk -> klaar om te lanceren (ARMED)
}

void loop() {
  switch (state) {

    case ARMED: {                                   // wachten op lancering
      float alt = relAltitude(bmp.readPressure() / 100.0);
      if (alt > LAUNCH_RISE_M) {
        logf = LittleFS.open(LOGPATH, "a");
        tStart = millis();
        lastSample = micros();
        maxAlt = alt;
        state = LOGGING;
      }
      led((millis() / 500) % 2);                    // langzaam knipperen = gereed
    } break;

    case LOGGING: {                                 // op vaste frequentie loggen
      if (micros() - lastSample >= SAMPLE_US) {
        lastSample += SAMPLE_US;
        float pres = bmp.readPressure() / 100.0;
        float alt  = relAltitude(pres);
        float temp = bmp.readTemperature();
        uint32_t t = millis() - tStart;
#if USE_IMU
        sensors_event_t a, g, te;
        mpu.getEvent(&a, &g, &te);
        logf.printf("%lu,%.2f,%.2f,%.1f,%.2f,%.2f,%.2f\n",
                    t, alt, pres, temp,
                    a.acceleration.x, a.acceleration.y, a.acceleration.z);
#else
        logf.printf("%lu,%.2f,%.2f,%.1f\n", t, alt, pres, temp);
#endif
        if (alt > maxAlt) maxAlt = alt;             // apogeum bijhouden

        // landingsdetectie: laag en stabiel gedurende LAND_WINDOW_S
        if (alt < LAND_ALT_M && maxAlt > LAUNCH_RISE_M) landCount++;
        else landCount = 0;
        bool landed  = landCount > (LAND_WINDOW_S * SAMPLE_HZ);
        bool timeout = (millis() - tStart) > (MAX_LOG_S * 1000UL);

        if (landed || timeout) {
          logf.close();
          startAP();
          state = LANDED;
        }
        led(1);                                     // continu aan = aan het loggen
      }
    } break;

    case LANDED:                                    // AP actief, data downloadbaar
      server.handleClient();
      led((millis() / 150) % 2);                    // snel knipperen = klaar
      break;
  }
}

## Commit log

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2026-08-08 hardware: parametrische payloadhouder (bord + BMP388 + accu) toevoegen
    [PWS_Waterraket_Houder.scad]
2026-08-08 Repo compleet: Office-documenten, STL en logsheets toegevoegd, losse bestanden uit de hoofdmap verwijderd
    [PWS_Waterraket_Houder.stl, PWS_Waterraket_Logsheets.xlsx]
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2026-08-09 firmware: vaste touch-correctie van -22 px als standaard, oude ijking vervalt
    [PWS_Waterraket_ESP32-S3-Touch_sketch.ino]
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2026-08-09 firmware: SYS_EN 41 / SYS_OUT 40 en buzzer GPIO42 conform officiele Waveshare-documentatie
    [PWS_Waterraket_ESP32-S3-Touch_sketch.ino]
2026-08-09 hardware: ruimere payloadhouder met generatorscript en STL, handleiding aangevuld
    [PWS_Waterraket_Houder.stl]
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2026-08-09 hardware: houder op de werkelijke bordmaten (41,13 x 33,13 x 6,6 mm) uit de officiele maatschets
    [PWS_Waterraket_Houder.stl]
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2026-08-10 analyse-webapp: client-side applicatie, testdatagenerator met gauntlet-controles en formuledocument
    [PWS_Waterraket_Houder.3mf, vlucht_afgebroken.csv, vlucht_klipt.csv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]
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2026-08-22 hardware: neuskegel met payloadruimte, statische poorten en ogief-punt
    [PWS_Waterraket_Neuskegel_Bay.stl, PWS_Waterraket_Neuskegel_Tip.stl]
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2026-08-22 hardware: parametrische fin can in drie maten met bekend vinoppervlak
    [PWS_Waterraket_Vinnen_groot.stl, PWS_Waterraket_Vinnen_klein.stl, PWS_Waterraket_Vinnen_midden.stl]
2026-08-23 standaardfles vastgelegd: Lipton Ice Tea 1,5 L (band 88,5 mm, taille ~81 mm); STL's op 88,5 hergenereerd
    [PWS_Waterraket_Neuskegel_Bay.stl, PWS_Waterraket_Neuskegel_Tip.stl, PWS_Waterraket_Vinnen_groot.stl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]
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2026-08-24 hardware: adapter voor Raketfued Phoenix 3D d78m recovery (spigot uit opgemeten casingprofiel)
    [PWS_Waterraket_Phoenix_Adapter.stl]
2026-08-28 hardware: eigen recovery met servo-zijdeur (Phoenix-principe, parametrisch), passing numeriek bewezen
    [PWS_Waterraket_Recovery_Deur.stl, PWS_Waterraket_Recovery_Romp.stl]
2026-08-28 recovery: fles schuift 50 mm diep in de romp; materiaal- en printadvies aangevuld
    [PWS_Waterraket_Recovery_Deur.stl, PWS_Waterraket_Recovery_Romp.stl]
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2026-08-29 vinnen: conische binnenboring die de taps toelopende flesvorm volgt (84,0 -> 88,5 mm over 30 mm)
    [PWS_Waterraket_Vinnen_groot.stl, PWS_Waterraket_Vinnen_klein.stl, PWS_Waterraket_Vinnen_midden.stl]
2026-08-29 vinnen: krappere zitting (87,9 mm uit omtrek 276, speling 0,4 mm)
    [PWS_Waterraket_Vinnen_groot.stl, PWS_Waterraket_Vinnen_klein.stl, PWS_Waterraket_Vinnen_midden.stl]
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2026-08-29 hardware: testneus in TPU voor vluchten zonder parachute
    [PWS_Waterraket_Testneus.stl]
2026-08-30 hardware: nozzles in twee uitvoeringen (insteek in geboorde dop en volledig geprinte PCO1881-dop)
    [PWS_Waterraket_Nozzle_04mm.stl, PWS_Waterraket_Nozzle_05mm.stl, PWS_Waterraket_Nozzle_06mm.stl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]
2026-08-30 hardware: Gardena-nozzles met geleidingsbossing en vlakke zitting, steel opgemeten uit Raketfued
    [PWS_Waterraket_NozzleGardena_04mm.stl, PWS_Waterraket_NozzleGardena_05mm.stl, PWS_Waterraket_NozzleGardena_06mm.stl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]
2026-08-30 hardware: Gardena-nozzle in geboorde originele dop - geen geprinte draad, geen inwendig support
    [PWS_Waterraket_NozzleGardenaDop_04mm.stl, PWS_Waterraket_NozzleGardenaDop_05mm.stl, PWS_Waterraket_NozzleGardenaDop_06mm.stl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]
2026-08-30 hardware: Gardena-nozzles met zitting op de steunring - bredere referentie, geen support nodig
    [PWS_Waterraket_NozzleSteunring_04mm.stl, PWS_Waterraket_NozzleSteunring_05mm.stl, PWS_Waterraket_NozzleSteunring_06mm.stl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]
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2026-09-11 recovery: parachutekamer naar 85 mm zodat de romp (247 mm) op een X1 past
    [PWS_Waterraket_Recovery_Romp.stl, PWS_Waterraket_Recovery_Romp_Boven.stl, PWS_Waterraket_Recovery_Romp_Onder.stl]
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2026-09-11 recovery: verwisselbare schroefneus in drie vormen, los schotje voor toegang, deur passend gemaakt
    [PWS_Waterraket_Neus_Elliptisch.stl, PWS_Waterraket_Neus_Kegel.stl, PWS_Waterraket_Neus_Ogief.stl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]
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2026-10-01 hardware: nozzle als opzetstuk over de originele dop, haakt onder de steunring
    [PWS_Waterraket_NozzleOpzet_04mm.stl, PWS_Waterraket_NozzleOpzet_05mm.stl, PWS_Waterraket_NozzleOpzet_06mm.stl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]
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2026-10-03 recovery: tangent-ogief met dichte top, servo liggend buiten de draadzone, kamer 100 mm, pengat ingekort
    [PWS_Waterraket_Neus_Elliptisch.stl, PWS_Waterraket_Neus_Kegel.stl, PWS_Waterraket_Neus_Ogief.stl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]
2026-10-03 compact: platte elektronicatray, servo naast de deur, kortere neus; scharnier herbouwd met tangentiele as
    [PWS_Waterraket_Houder.stl, PWS_Waterraket_Neus_Elliptisch.stl, PWS_Waterraket_Neus_Kegel.stl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]
2026-10-03 recovery: deur 14 mm boven de vloer (schot vrij van scharnier), wig onder het servoplankje
    [PWS_Waterraket_Recovery_Deur.stl, PWS_Waterraket_Recovery_Romp.stl]
2026-10-04 neus: rekenfout in de draadkern verholpen (lag boven de rompruggen); proefstukken voor de draad
    [PWS_Waterraket_Neus_Elliptisch.stl, PWS_Waterraket_Neus_Kegel.stl, PWS_Waterraket_Neus_Ogief.stl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]
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2026-10-04 schotje en tray in helften: pasten door geen enkele opening; nieuwe controle op inbrengbaarheid
    [PWS_Waterraket_Recovery_Schot.stl, PWS_Waterraket_Recovery_Schot_A.stl, PWS_Waterraket_Recovery_Schot_B.stl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]
